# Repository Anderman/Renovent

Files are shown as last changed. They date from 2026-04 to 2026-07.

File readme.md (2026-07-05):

# Renovent 

## Installatie Screenshot
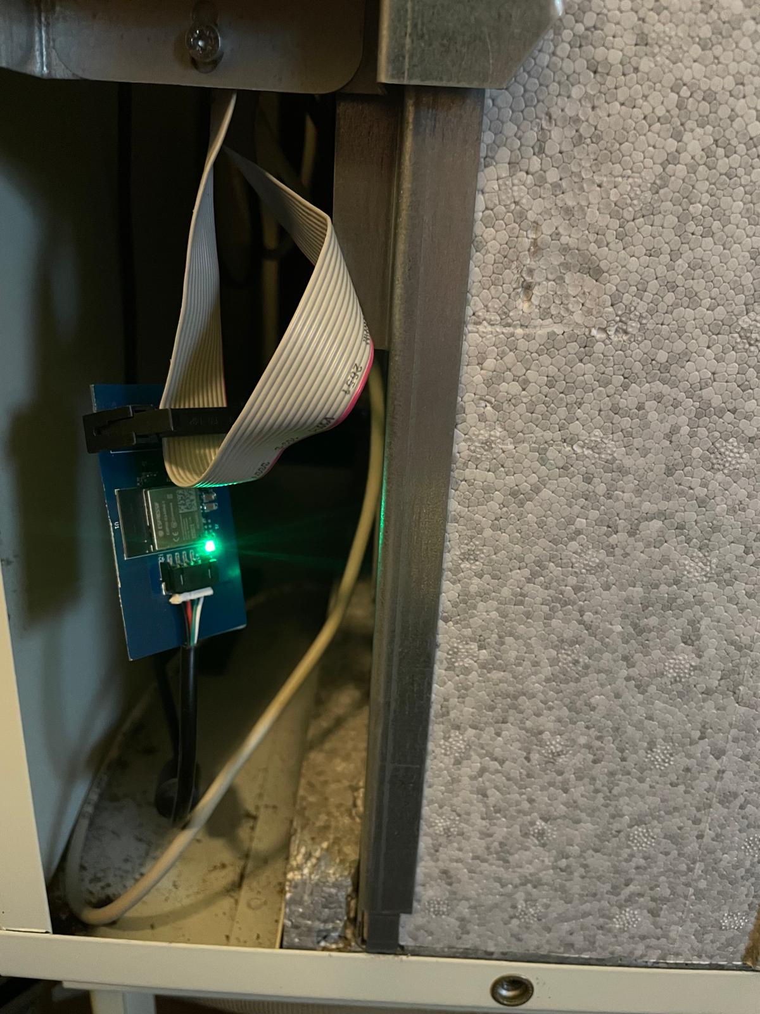
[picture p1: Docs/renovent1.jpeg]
Installatie connector aan flatkabel

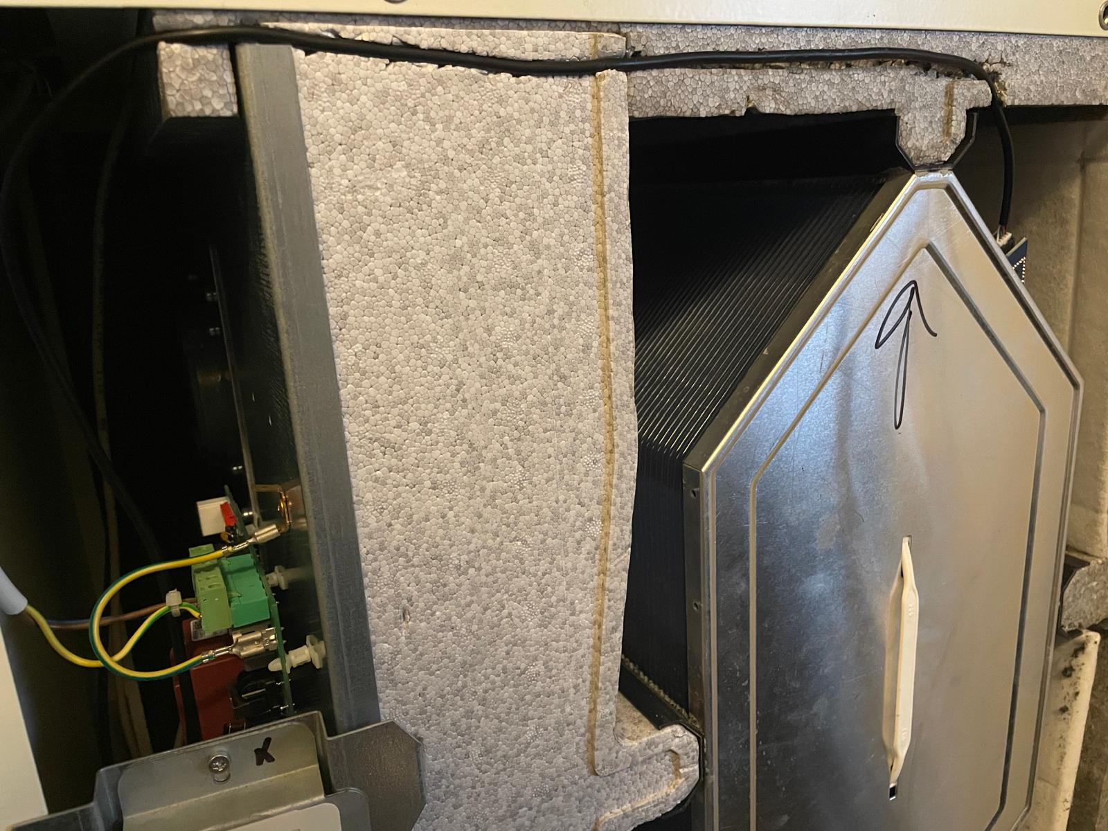
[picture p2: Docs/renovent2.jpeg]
Co2 sensor plaatsen


## Web interface
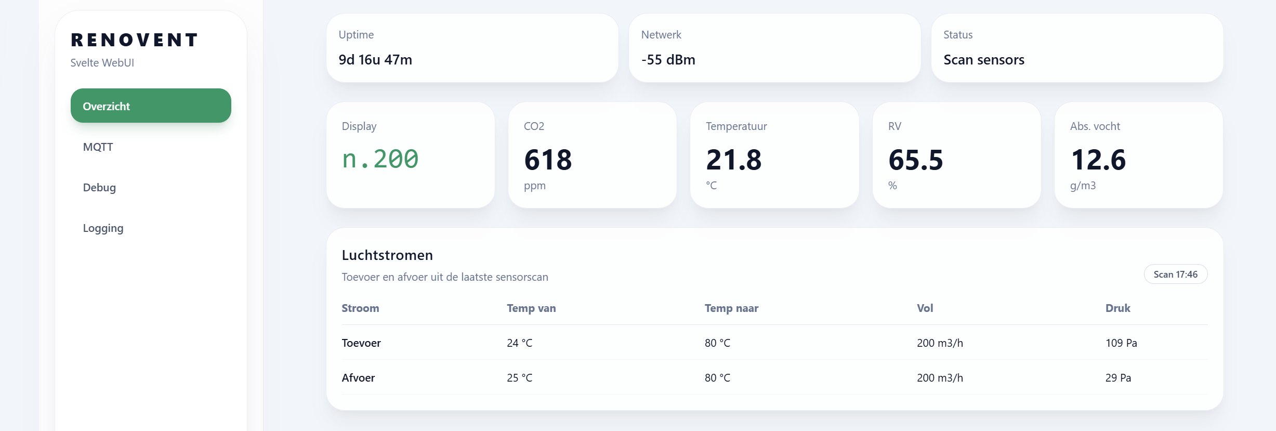
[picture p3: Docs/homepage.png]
homepage

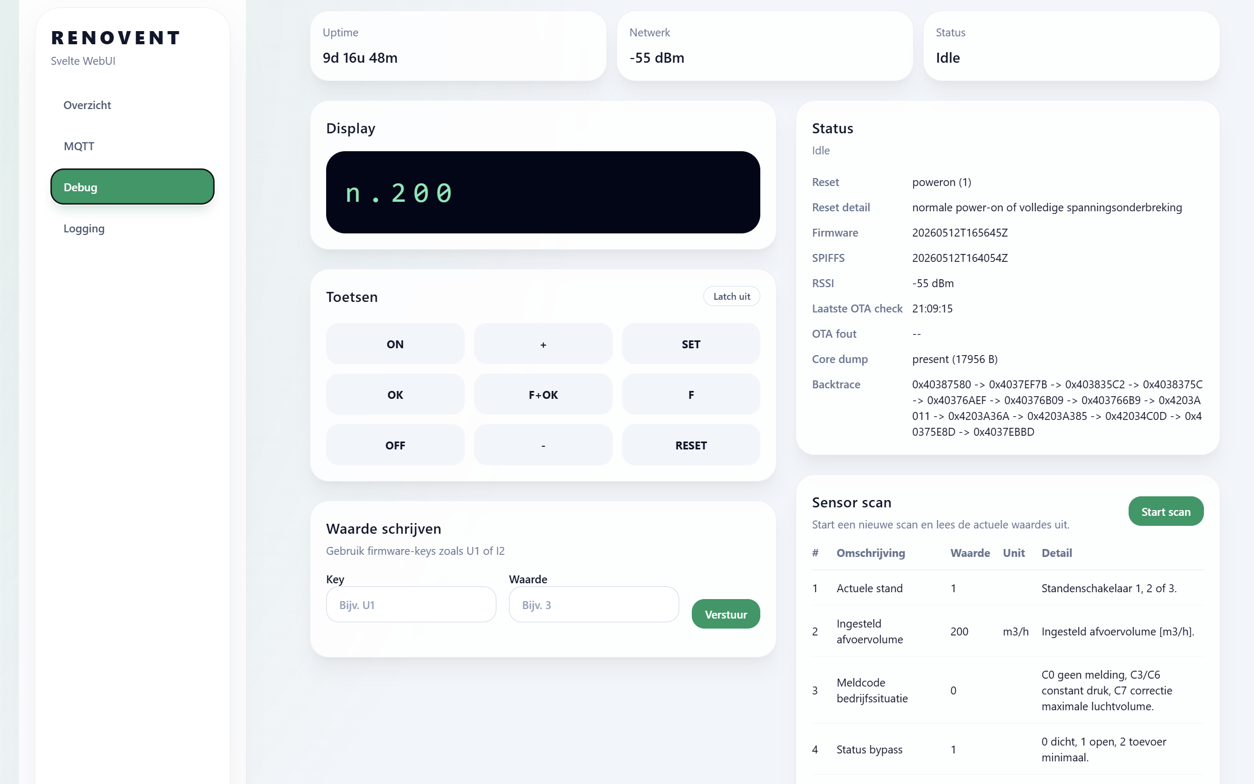
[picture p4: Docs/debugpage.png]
debug


## homeassistant
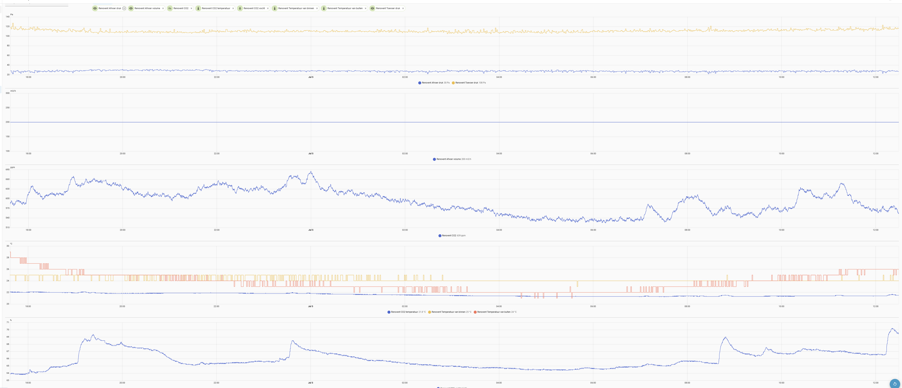
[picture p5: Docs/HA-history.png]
History

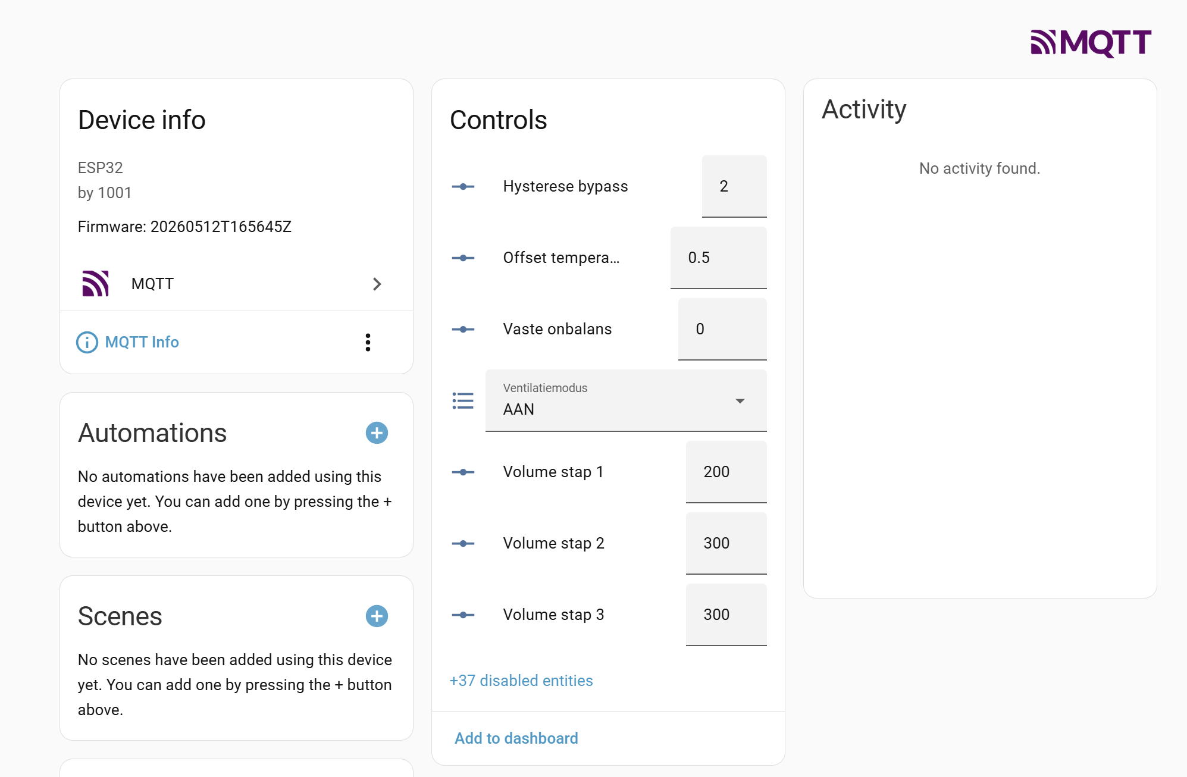
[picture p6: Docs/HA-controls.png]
Controls

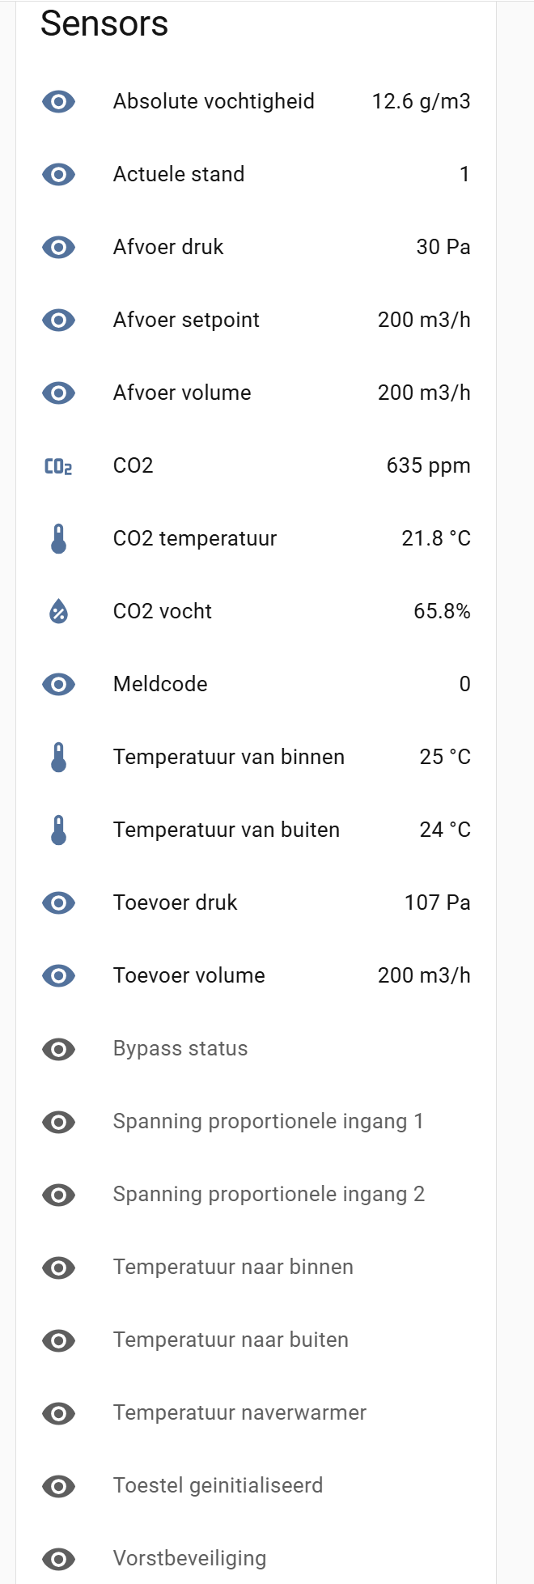
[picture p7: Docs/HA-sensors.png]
Sensors


# software documentatie
De originele controller is een display met toetsen en 1 IC
De IC zet een 3 bit counter om in 8 select lijnen van het display.

Display is een  [liteon](https://eu.mouser.com/datasheet/3/281/1/LTC_4627JS.pdf)
De 8 segementen worden in volgorde aan gestuurd met een freq van 500uS
Welke segmenten verlicht worden gaat met digit 1 - 4

Het programma zal dus het continue het display moeten uitlezen en wat er op staat omzetten in een 4 char array.
Hiervan met gebruik gemaakt worden van mapping om een 8 bit array om te zetten in een Char. Waarschijnlijk kan de DP los en hebben we een 7 bitarray naar char mapping nodig.

De switches werken als volgt

Er is 1 output Key_node.
sw1 (OK) = key_node=1 als C=1 (counter=1)
Sw2 (+ ) = key_node=1 als D=1 (counter=5)
Sw3 (F ) = key_node=1 als E=1 (counter=6)
Sw4 (- ) = key_node=1 als DP=1 (counter=3)

## ESP32 aansluiting

In het ESP32-schema worden de relevante signalen van de originele controller eerst via een SN74LVC245 naar 3V3 gebracht. De ESP32 ziet dus alleen de 3V3-varianten van deze signalen.

### Ingangen voor het uitlezen van display en toetsen

- BIT0 -> BIT0_3V3 -> GPIO35
- BIT1 -> BIT1_3V3 -> GPIO36
- BIT2 -> BIT2_3V3 -> GPIO37
- Digit1 -> Digit1_3V3 -> GPIO38
- Digit2 -> Digit2_3V3 -> GPIO39
- Digit3 -> Digit3_3V3 -> GPIO40
- Digit4 -> Digit4_3V3 -> GPIO41
- KEY_NODE -> KEY_NODE_3V3 -> GPIO42

Deze acht ingangen zijn voldoende om het gemultiplexte display en de toetsstatus te reconstrueren.

### Uitgang voor toets simulatie

- KEY_DOWN <- GPIO43

KEY_DOWN gaat via een BSS138-transistor naar de originele schakeling. Daarmee kan de ESP32 een toetsdruk simuleren zonder direct 5V op een GPIO te zetten.

### Overige aansluitingen op het ESP32-bord

- SDA_1 -> GPIO7
- SCL_1 -> GPIO8
- LED -> GPIO12

## Aanpak in software

De displaycontroller loopt elke 500 us door de 8 segment-selects. De software leest dus niet "digit 1", daarna "digit 2", enzovoort, maar leest per segment-select in een keer de toestand van alle 4 digitlijnen.

Concreet:

1. `BIT0`, `BIT1` en `BIT2` vormen samen een tellerwaarde van `0..7`.
2. Die tellerwaarde bepaalt welk segment op dat moment actief is.
3. Tegelijk wordt gekeken welke van `Digit1..Digit4` hoog zijn.
4. Voor het actieve segment wordt dat bit gezet in alle digits die op dat moment hoog zijn.
5. Na 8 select-stappen is er een compleet 4-digit frame opgebouwd.

De mapping van de tellerwaarde naar segment is:

| BIT2 BIT1 BIT0 | index | segment |
| --- | --- | --- |
| 0 0 0 | 0 | A |
| 0 0 1 | 1 | C |
| 0 1 0 | 2 | B |
| 0 1 1 | 3 | DP |
| 1 0 0 | 4 | F |
| 1 0 1 | 5 | D |
| 1 1 0 | 6 | E |
| 1 1 1 | 7 | G |

Schematisch ziet een volledige scan er zo uit:

```mermaid
flowchart LR
	A[GPIO snapshot] --> B[Lees BIT0..2]
	B --> C[Select-index 0..7]
	C --> D[Segment voor deze stap kiezen]
	D --> E{Lees Digit1..4 in dezelfde snapshot}
	E --> F[Zet dit ene segment in digit 1..4 als die hoog zijn]
	F --> G[Werk lopend frame bij]
	G --> H{Zijn alle 8 select-stappen gezien?}
	H -- nee --> A
	H -- ja --> I[4 complete digitmasks klaar]
	I --> J[Zet digitmasks om naar displaytekst]
```

Eén interrupt-snapshot doet dus niet alles. Per snapshot gebeurt maar dit:

- bepaal welk segment nu actief is via `BIT0..2`
- lees tegelijk welke van de 4 digitlijnen actief zijn
- zet dat ene segment in de digits die op dat moment hoog zijn

Pas nadat dit 8 keer gebeurd is, hebben we voor alle 4 digits een volledig segmentmasker.

Je kunt het ook zo lezen: we lezen niet "4 displays na elkaar", maar per segment in een keer alle 4 displays.

Voorbeeld:

- `BIT2..0 = 000` betekent segment `A`
- als op dat moment `Digit1` en `Digit3` hoog zijn, dan krijgt digit 1 en digit 3 het segment `A`
- bij de volgende select-stap wordt bijvoorbeeld segment `C` op dezelfde manier verdeeld over de 4 digits
- na alle 8 segmenten kennen we van elke digit het volledige segmentmasker

`KEY_NODE` wordt in diezelfde scan meegelezen. Een actieve key tijdens een specifieke select-index betekent een specifieke toets.

## Interrupt of polling

De huidige implementatie gebruikt juist een interrupt op `BIT0`.

Waarom:

- de select-bits veranderen snel genoeg dat polling onnodig veel jitter gaf
- de reader wil alle relevante lijnen op exact hetzelfde moment samplen
- daarom leest de ISR direct een volledige GPIO-snapshot en reconstrueert daaruit de actuele select-index, digitlijnen en `KEY_NODE`

De implementatie in `src/display_reader.cpp` werkt zo:

1. `BIT0` triggert `onBit0ChangeInterrupt()` op elke flank.
2. De ISR leest direct `GPIO.in1.val`, zodat alle ingangssignalen uit hetzelfde tijdsmoment komen.
3. Uit `BIT0..2` wordt de verwachte select-index bepaald.
4. Als een select-stap ontbreekt of de volgorde niet klopt, wordt het huidige frame weggegooid.
5. Na select `7` is een volledig frame klaar.
6. De hoofdloop publiceert pas een frame als twee opeenvolgende complete frames gelijk zijn.

Daardoor is de reader robuuster tegen timingglitches en worden half-opgebouwde displaybeelden niet gepubliceerd.

## Huidige softwarebasis

Er is nu een eerste ESP32 software-opzet toegevoegd in de map `src`.

- `src/main.cpp` start WiFi, de webserver en de display reader.
- `src/wifiSetup.*` gebruikt WiFiManager, net als in het andere project.
- `src/display_reader.*` leest BIT0..2, Digit1..4 en KEY_NODE in en bouwt daar een stabiel displayframe van op.
- `src/webui/webui.*` publiceert een simpele HTTP API en serveert statische bestanden uit SPIFFS.
- `data/index.html` is een eenvoudige debugpagina.

### Webinterface

Na boot:

- hoofd-UI op poort 80
- WiFiManager portal op poort 8080

Beschikbare endpoints:

- `GET /api/status`
- `POST /api/keydown`

`/api/status` geeft onder andere terug:

- gedecodeerde displaytekst
- actieve toets op basis van `KEY_NODE`
- WiFi-status

### PlatformIO

Er is ook een `partitions/default.csv` toegevoegd zodat de SPIFFS data-partitie beschikbaar is voor de webpagina.

Voor lokaal gebruik zijn deze commando's relevant:

1. `platformio run`
2. `platformio run --target buildfs`
3. `platformio run --target uploadfs`
4. `platformio run --target upload`

### OTA artifacts lokaal bouwen

De automatische firmware-update leest OTA-bestanden uit `release/firmware`, `release/spiffs` en `release/latest.json`.

Deze artifacts worden lokaal gegenereerd door `scripts/generate_build_info.py`, dat als PlatformIO build hook meeloopt. De hook:

- berekent een aparte hash voor `src` en `data`
- bewaart per component precies een markerbestand `*.hash` in `src` en `ui-hashes`
- schrijft alleen een nieuwe build-id als de hash van die component gewijzigd is
- kopieert de nieuwe `.bin` naar `release/firmware` of `release/spiffs`
- werkt daarna `release/latest.json` bij

Voor een volledige lokale OTA release bouw je beide artifacts:

1. `platformio run -e esp32s3mini_ota`
2. `platformio run -e esp32s3mini_ota -t buildfs`

Daarna kun je de bijgewerkte bestanden in `release/` zelf committen of op een andere manier publiceren, zolang `release/latest.json` en de bijbehorende `.bin` bestanden bereikbaar blijven voor de ESP32.

### Backtrace decoderen

Een ESP32-S3 backtrace uit de WebUI of seriele output kun je direct tegen de actuele firmware-ELF symboliseren met:

```powershell
.\scripts\decode_backtrace.ps1 "0x4037EF71 -> 0x40377C96 -> 0x40376AEF"
```

Het script gebruikt standaard:

- `.pio/build/esp32s3mini_ota/firmware.elf`
- de PlatformIO `xtensa-esp32s3-elf-addr2line.exe`

Belangrijk: decode altijd tegen de ELF van dezelfde firmware-build als waarmee de crash is ontstaan, anders kloppen functies en regelnummers mogelijk niet.

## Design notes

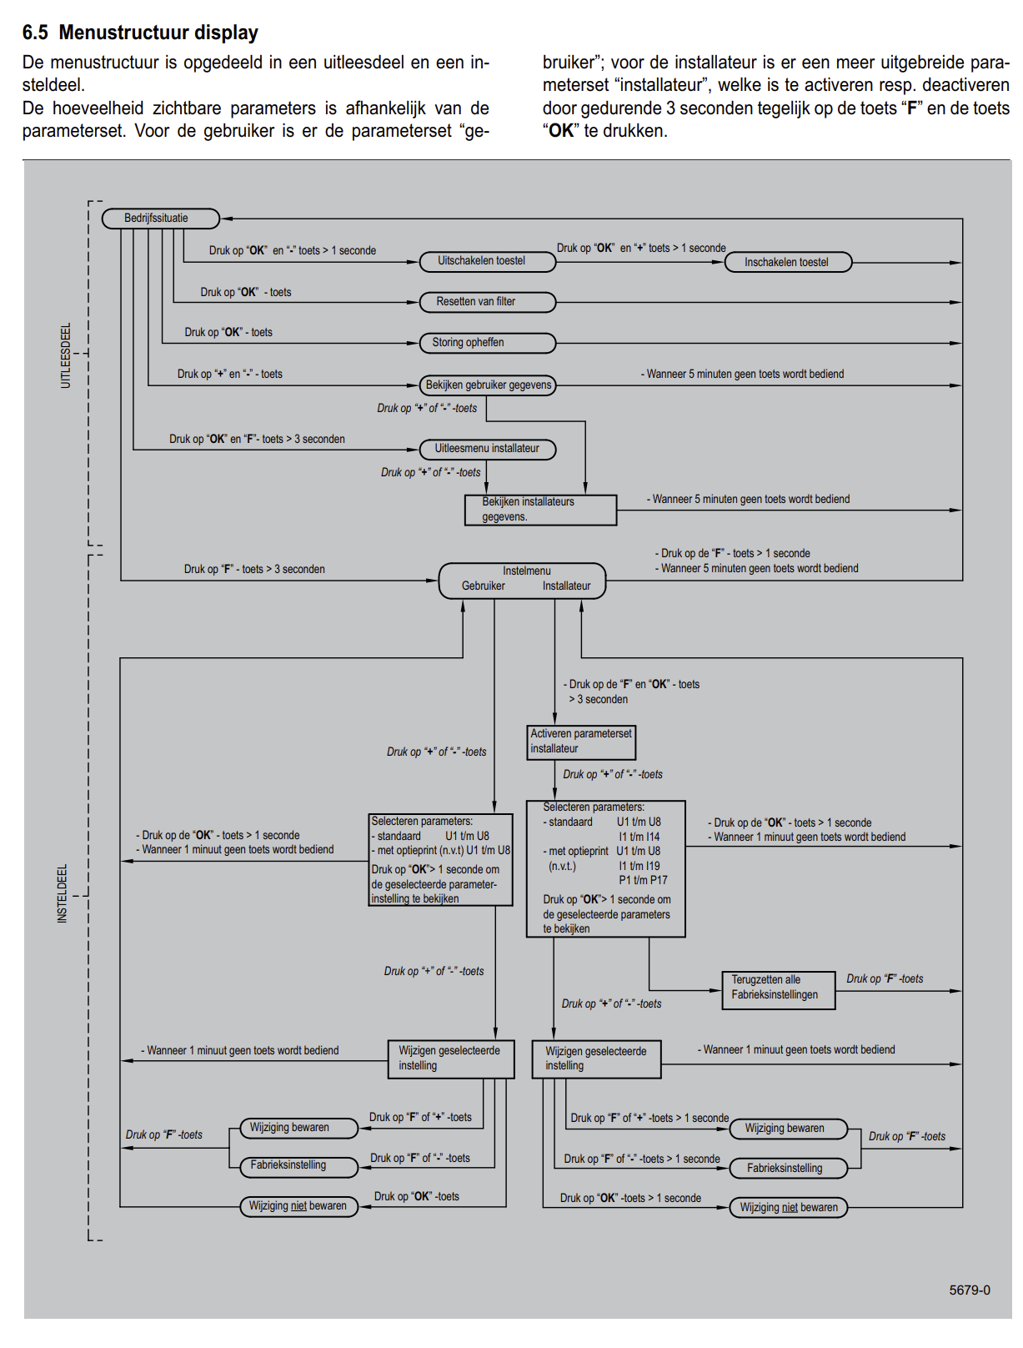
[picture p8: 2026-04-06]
Docs/H6 P20.png

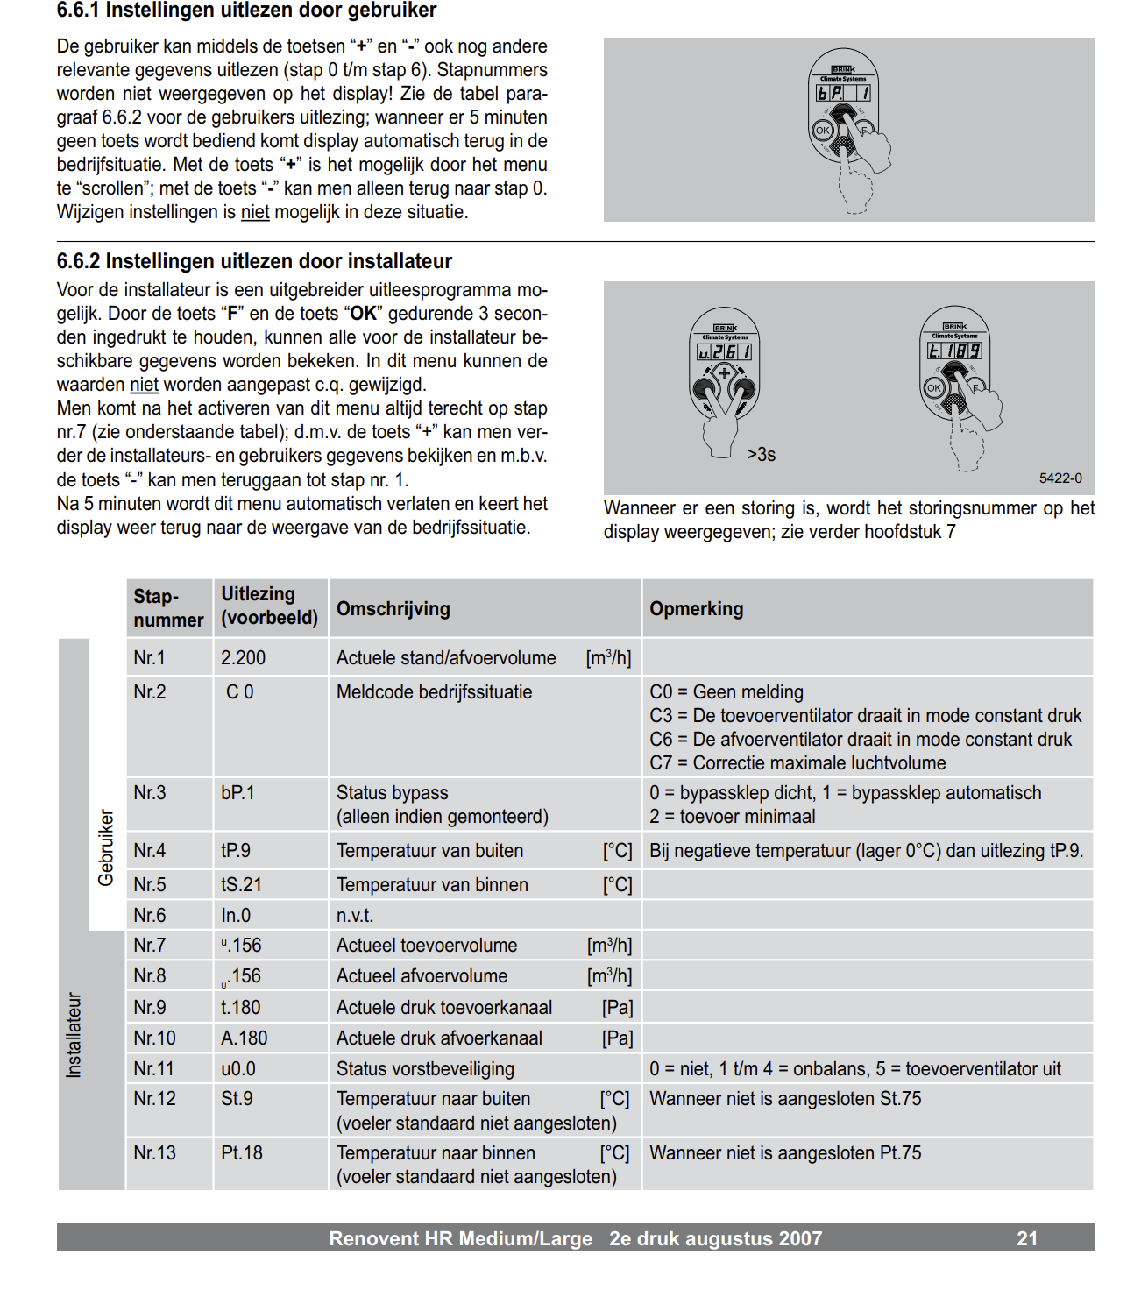
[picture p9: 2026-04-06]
Docs/H6 p21.png

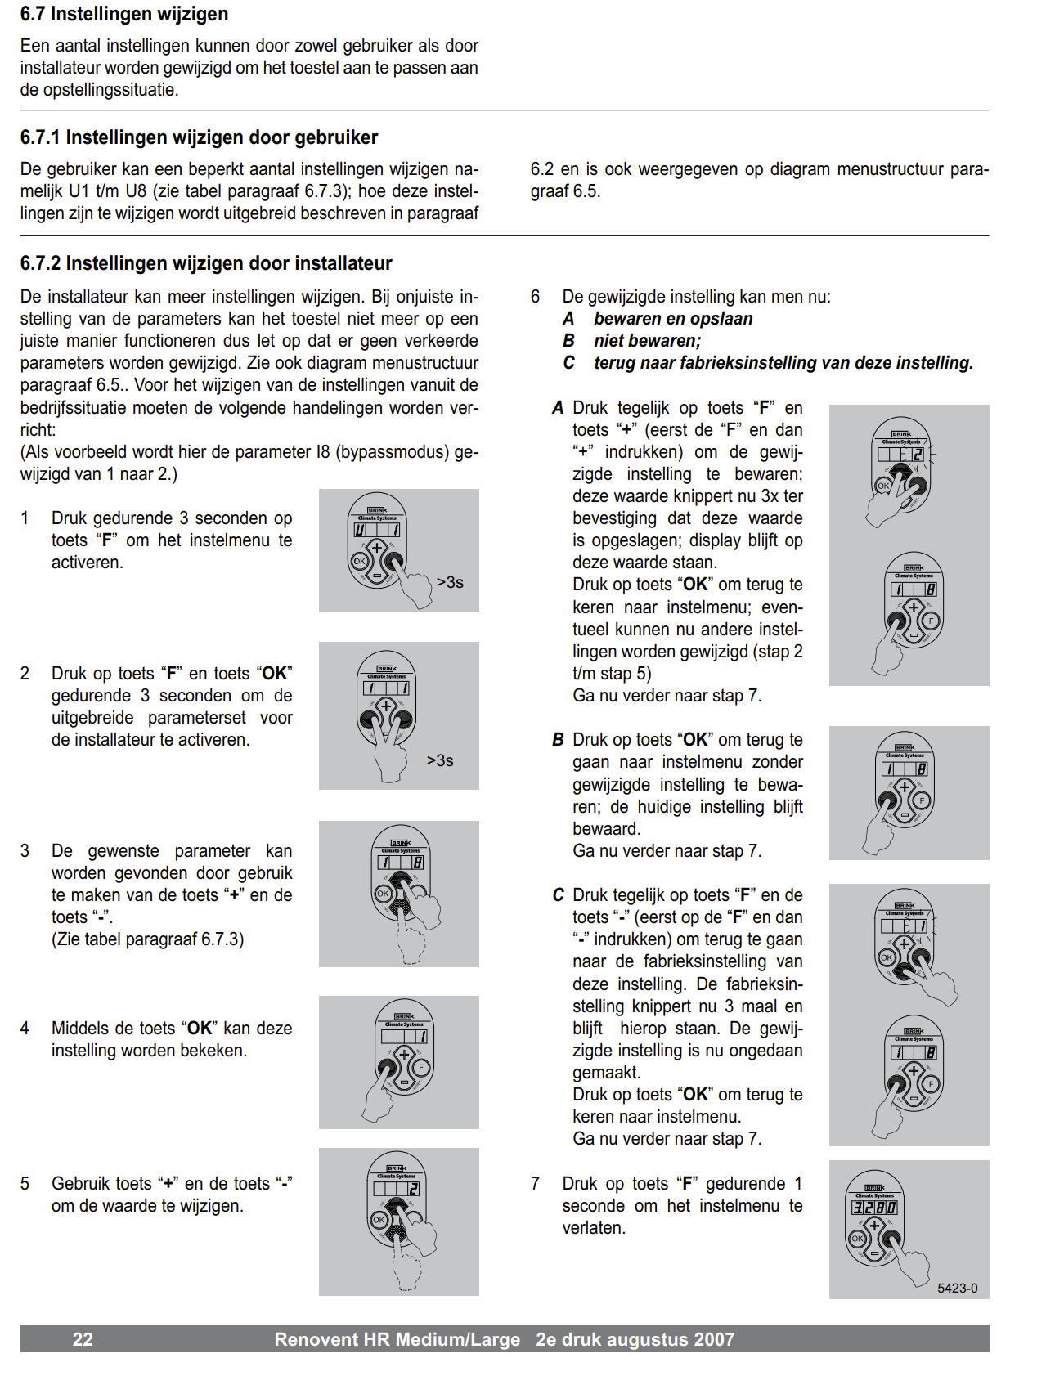
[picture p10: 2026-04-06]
Docs/H6 p22.png

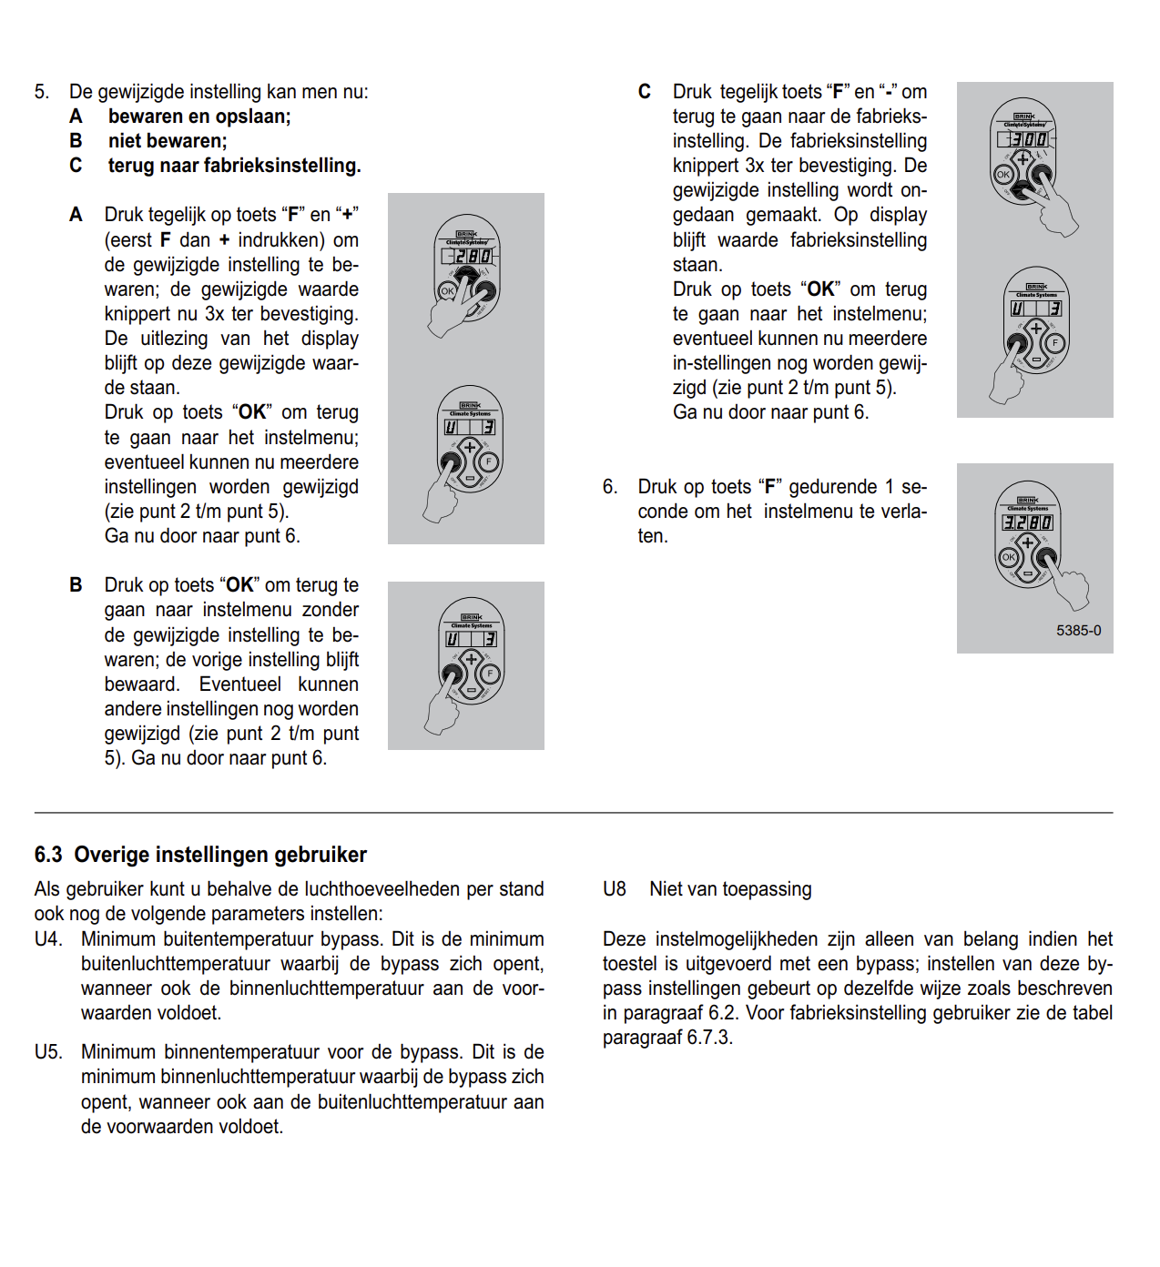
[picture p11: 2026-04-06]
Docs/H6 p18.png

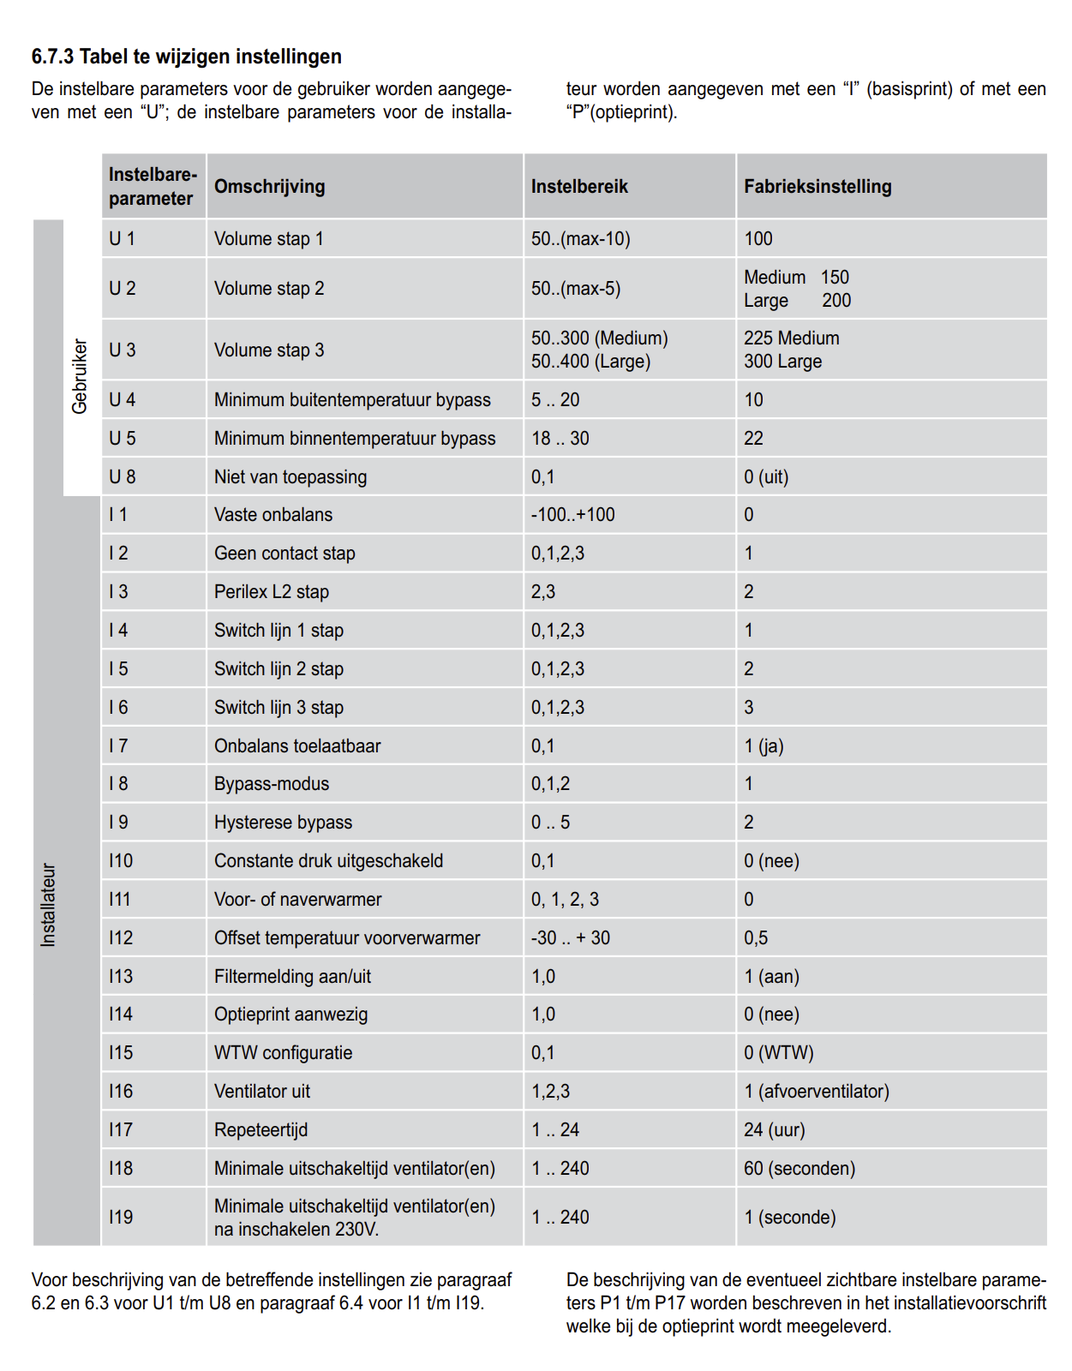
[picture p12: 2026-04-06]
Docs/H6 P23.png

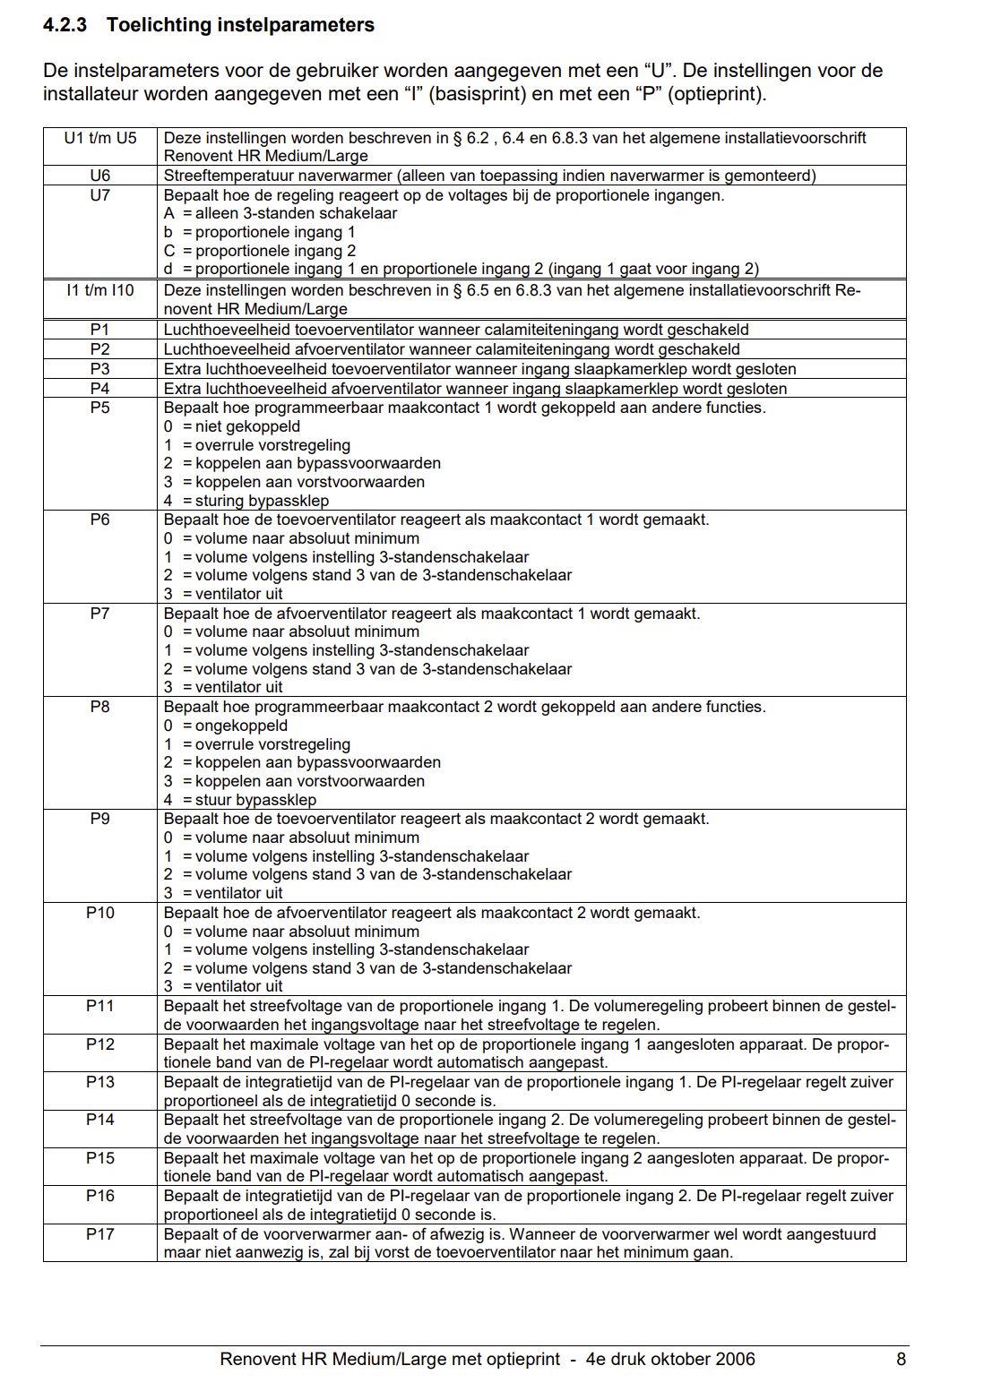
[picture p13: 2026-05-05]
Docs/4.3.2 P8.png

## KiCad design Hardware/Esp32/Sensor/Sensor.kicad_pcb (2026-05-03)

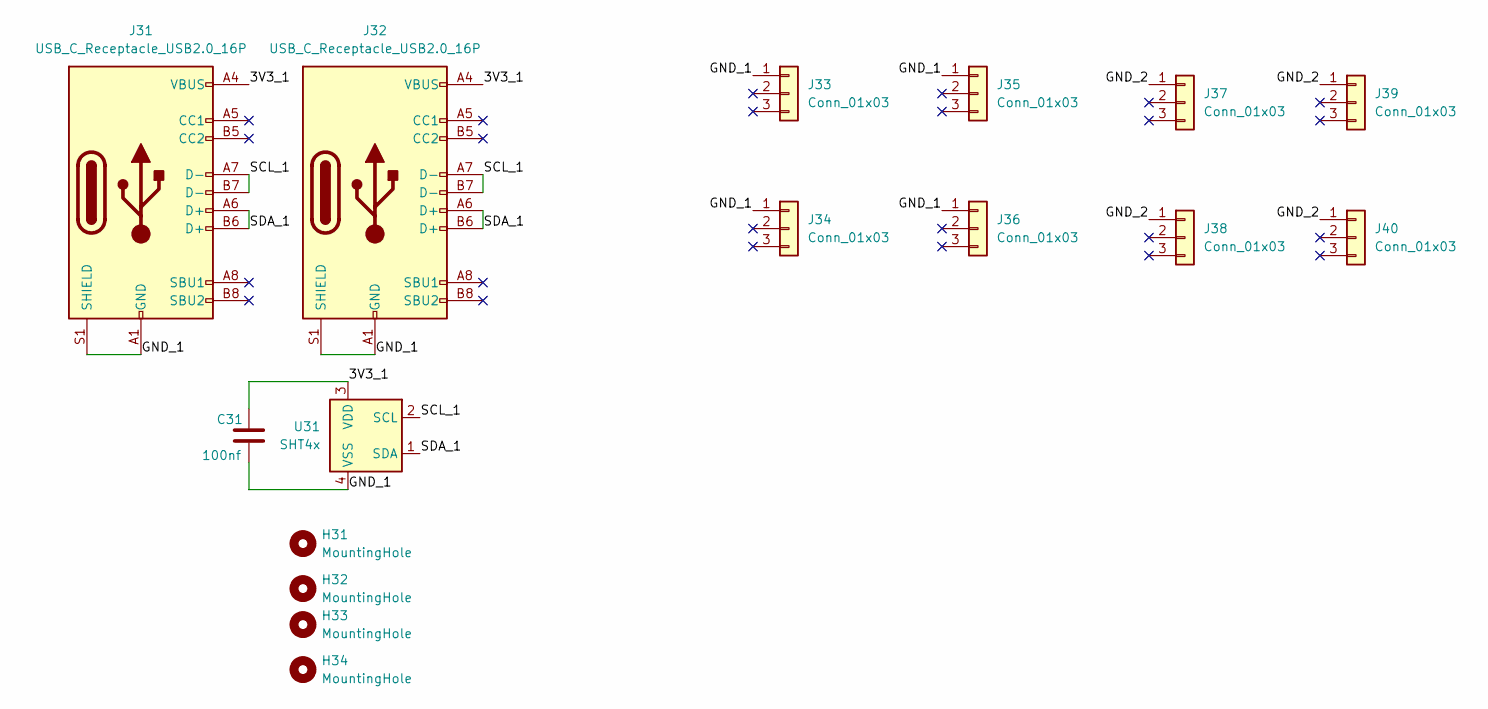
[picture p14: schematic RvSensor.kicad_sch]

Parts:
C31: 100nf; C_0402_1005Metric; LCSC C1525
H31, H32, H33, H34: MountingHole; MountingHole_2.5mm
J31, J32: USB_C_Receptacle_USB2.0_16P; USB_C_Receptacle_HRO_TYPE-C-31-M-12; LCSC C36936538
J33, J34, J35, J36: Conn_01x03; PinSocket_1x03_P2.00mm_Vertical_female_C2935967; LCSC C2935967
J37, J38, J39, J40: Conn_01x03; PinHeader_1x03_P2.00mm_Vertical_male_C541857; LCSC C541857
U31: SHT4x; Sensirion_DFN-4_1.5x1.5mm_P0.8mm_SHT4x_NoCentralPad; LCSC C7461852

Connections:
/RvSensor/3V3_1: C31.1, J31.A4 (VBUS), J31.A9 (VBUS), J31.B4 (VBUS), J31.B9 (VBUS), J32.A4 (VBUS), J32.A9 (VBUS), J32.B4 (VBUS), J32.B9 (VBUS), U31.3 (VDD)
/RvSensor/GND_1: C31.2, J31.A1 (GND), J31.A12 (GND), J31.B1 (GND), J31.B12 (GND), J31.S1 (SHIELD), J32.A1 (GND), J32.A12 (GND), J32.B1 (GND), J32.B12 (GND), J32.S1 (SHIELD), J33.1, J34.1, J35.1, J36.1, U31.4 (VSS)
/RvSensor/GND_2: J37.1, J38.1, J39.1, J40.1
/RvSensor/SCL_1: J31.A7 (D-), J31.B7 (D-), J32.A7 (D-), J32.B7 (D-), U31.2 (SCL)
/RvSensor/SDA_1: J31.A6 (D+), J31.B6 (D+), J32.A6 (D+), J32.B6 (D+), U31.1 (SDA)

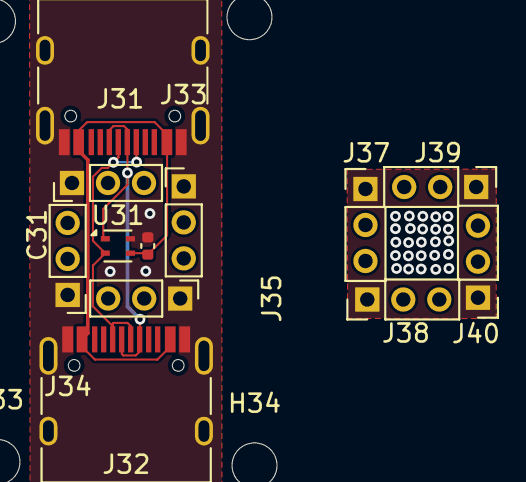
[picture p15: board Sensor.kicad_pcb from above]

Board: 2 copper layers, 16 parts (0 on the bottom side), 5 nets.

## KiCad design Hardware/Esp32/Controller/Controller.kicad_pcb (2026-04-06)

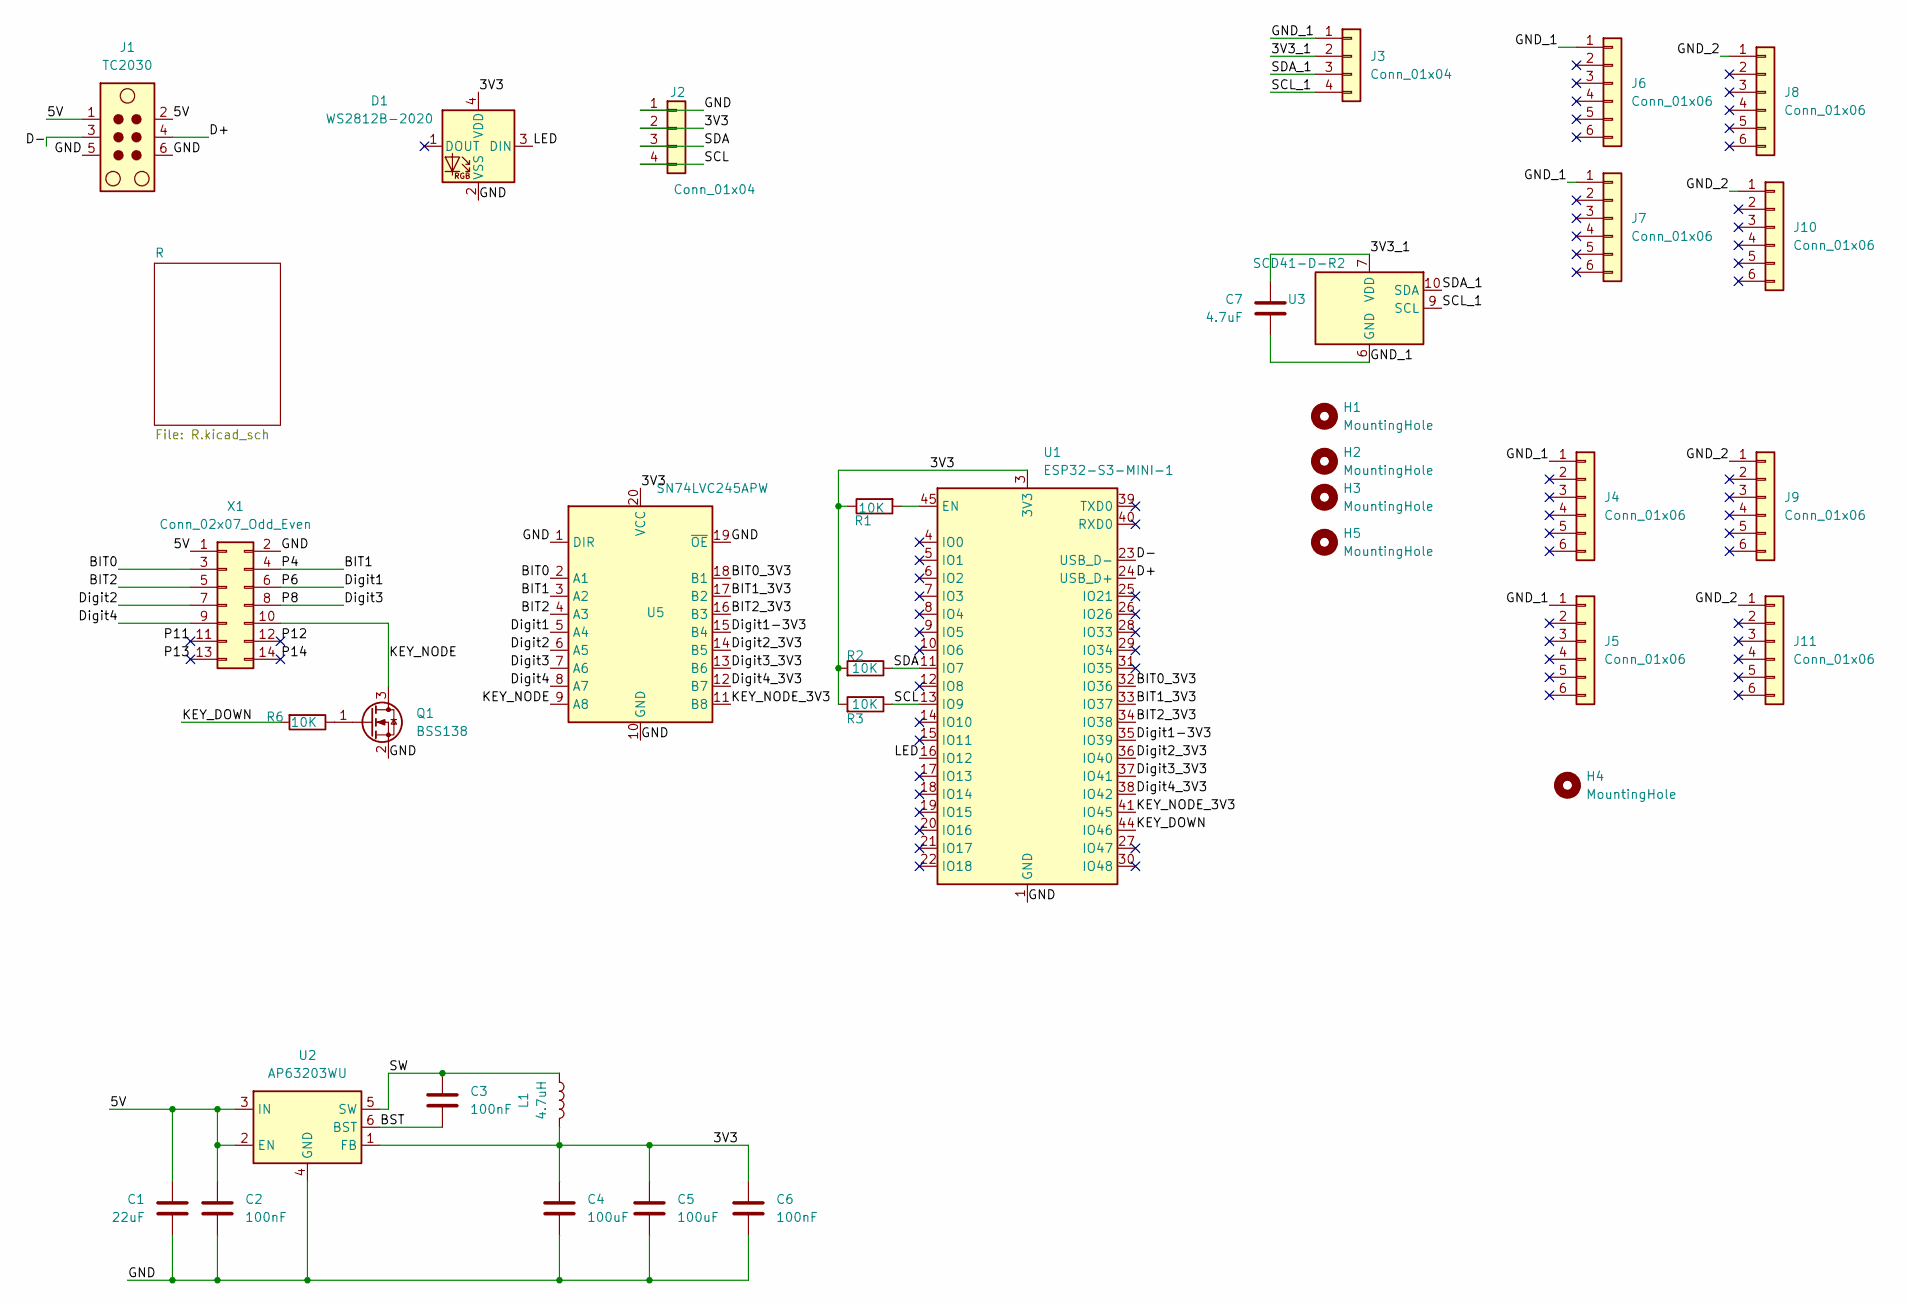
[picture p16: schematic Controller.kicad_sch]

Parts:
C1: 22uF; C_0805_2012Metric; LCSC C5674
C2, C3: 100nF; C_0603_1608Metric; LCSC C56476
C4, C5: 100uF; C_1206_3216Metric; LCSC C15008
C6: 100nF; C_0201_0603Metric; LCSC C76934
C7: 4.7uF; C_0603_1608Metric; LCSC C19666
D1: WS2812B-2020; LED_WS2812B-2020_2x2.2mm; LCSC C965555
H1, H2, H3, H5: MountingHole; MountingHole_2.5mm
H4: MountingHole; MountingHole_7mm
J1: TC2030; Tag-Connect_TC2030-IDC-NL_2x03_P1.27mm_Vertical
J2, J3: Conn_01x04; JST_PH_S4B-PH-SM4-TB_1x04-1MP_P2.00mm_Horizontal; LCSC C157926
J4, J5, J6, J7: Conn_01x06; PinSocket_1x06_P2.00mm_Vertical_female_C7499363; LCSC C7499363
J8, J9, J10, J11: Conn_01x06; PinHeader_1x06_P2.00mm_Vertical_male_C706993; LCSC C706993
L1: 4.7uH; L_Bourns-SRN4018; LCSC C5159668
Q1: BSS138; SOT-23; LCSC C20917
R1, R2, R3, R6: 10K; R_0402_1005Metric; LCSC C25744
U1: ESP32-S3-MINI-1; LCSC C3013941
U2: AP63203WU; TSOT-23-6; LCSC C780769
U3: SCD41-D-R2; Sensirion_SCD4x-1EP_10.1x10.1mm_P1.25mm_EP4.8x4.8mm; LCSC C3659294
U5: SN74LVC245APW; TSSOP-20_4.4x6.5mm_P0.65mm; LCSC C45384750
X1: Conn_02x07_Odd_Even; IDC-Header_2x07_P2.54mm_Vertical; LCSC C9037

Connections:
/3V3: C4.1, C5.1, C6.1, D1.4 (VDD), J2.2, L1.2, R1.1, R2.2, R3.2, U1.3 (3V3), U2.1 (FB), U5.20 (VCC)
/3V3_1: C7.1, J3.2, U3.7 (VDD), U3.19 (VDD)
/5V: C1.1, C2.1, J1.1, J1.2, U2.2 (EN), U2.3 (IN), X1.1
/BIT0: U5.2 (A1), X1.3
/BIT0_3V3: U1.32 (IO36), U5.18 (B1)
/BIT1: U5.3 (A2), X1.4
/BIT1_3V3: U1.33 (IO37), U5.17 (B2)
/BIT2: U5.4 (A3), X1.5
/BIT2_3V3: U1.34 (IO38), U5.16 (B3)
/BST: C3.2, U2.6 (BST)
/D+: J1.4, U1.24 (USB_D+)
/D-: J1.3, U1.23 (USB_D-)
/Digit1: U5.5 (A4), X1.6
/Digit1-3V3: U1.35 (IO39), U5.15 (B4)
/Digit2: U5.6 (A5), X1.7
/Digit2_3V3: U1.36 (IO40), U5.14 (B5)
/Digit3: U5.7 (A6), X1.8
/Digit3_3V3: U1.37 (IO41), U5.13 (B6)
/Digit4: U5.8 (A7), X1.9
/Digit4_3V3: U1.38 (IO42), U5.12 (B7)
/GND: C1.2, C2.2, C4.2, C5.2, C6.2, D1.2 (VSS), J1.5, J1.6, J2.1, Q1.2 (S), U1.1 (GND), U1.2 (GND), U1.42 (GND), U1.43 (GND), U1.46 (GND), U1.47 (GND), U1.48 (GND), U1.49 (GND), U1.50 (GND), U1.51 (GND), U1.52 (GND), U1.53 (GND), U1.54 (GND), U1.55 (GND), U1.56 (GND), U1.57 (GND), U1.58 (GND), U1.59 (GND), U1.60 (GND), U1.61 (GND), U1.62 (GND), U1.63 (GND), U1.64 (GND), U1.65 (GND), U2.4 (GND), U5.1 (DIR), U5.10 (GND), U5.19 (~OE), X1.2
/GND_1: C7.2, J3.1, J4.1, J5.1, J6.1, J7.1, U3.6 (GND), U3.20 (GND), U3.21 (GND)
/GND_2: J8.1, J9.1, J10.1, J11.1
/KEY_DOWN: R6.2, U1.44 (IO46)
/KEY_NODE: Q1.3 (D), U5.9 (A8), X1.10
/KEY_NODE_3V3: U1.41 (IO45), U5.11 (B8)
/LED: D1.3 (DIN), U1.16 (IO12)
/P11: X1.11
/P12: X1.12
/P13: X1.13
/P14: X1.14
/SCL: J2.4, R3.1, U1.13 (IO9)
/SCL_1: J3.4, U3.9 (SCL)
/SDA: J2.3, R2.1, U1.11 (IO7)
/SDA_1: J3.3, U3.10 (SDA)
/SW: C3.1, L1.1, U2.5 (SW)
unnamed: Q1.1 (G), R6.1
unnamed: R1.2, U1.45 (EN)

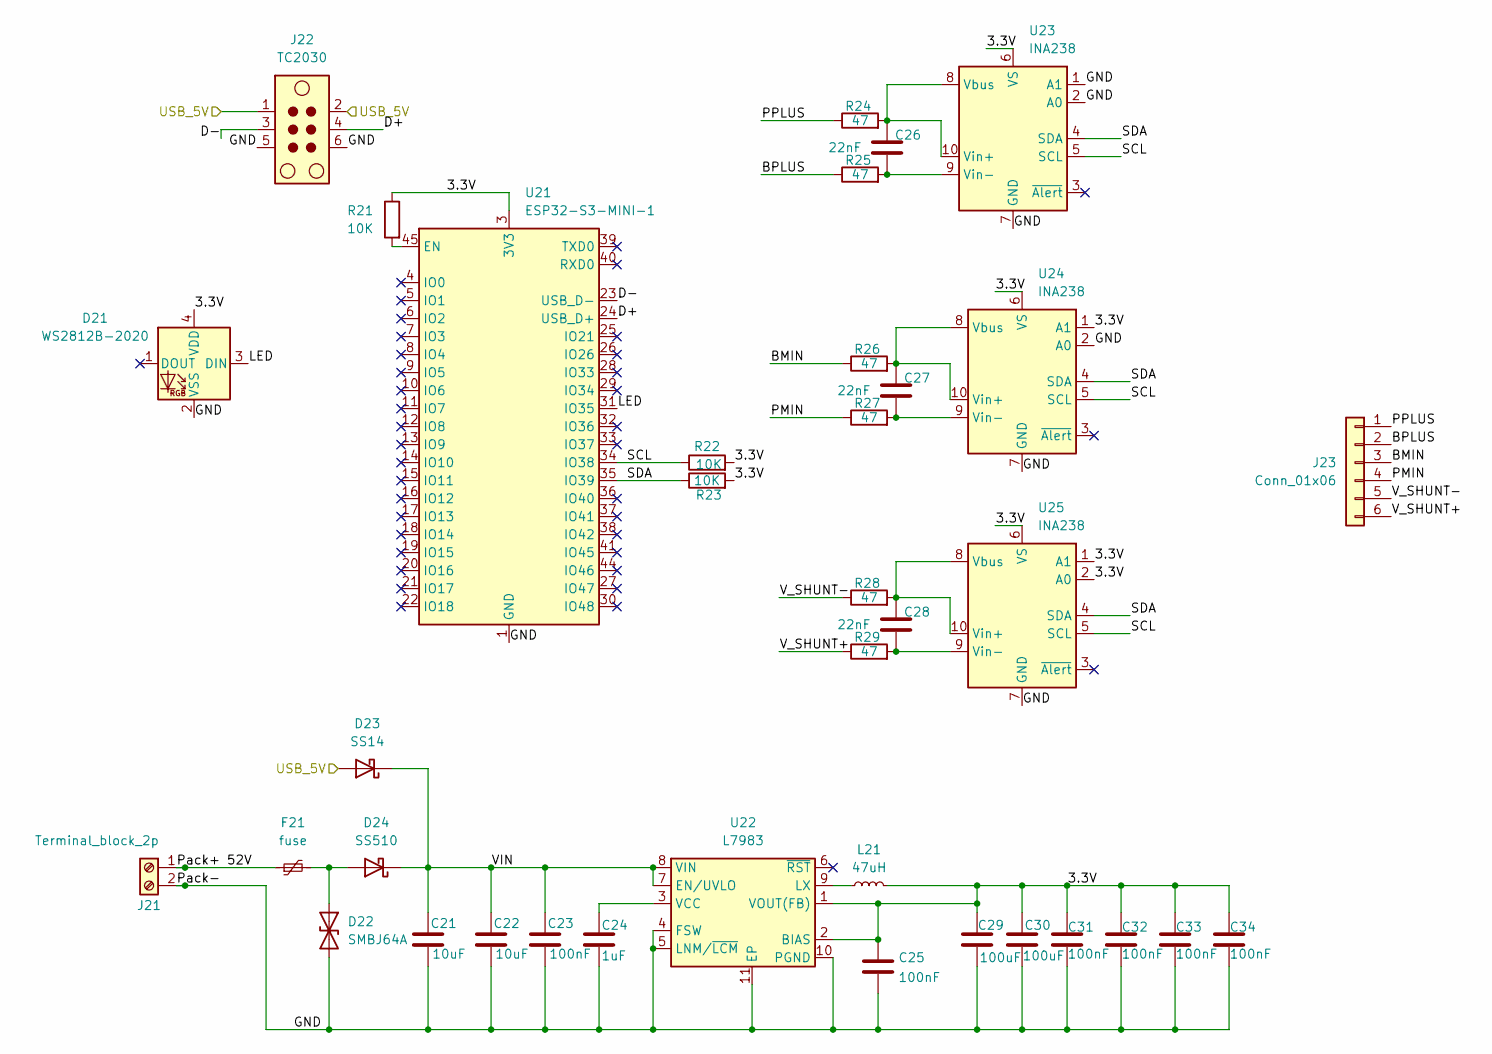
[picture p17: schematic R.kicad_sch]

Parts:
C21, C22: 10uF; C_1210_3225Metric; LCSC C576517
C23: 100nF; C_0402_1005Metric; LCSC C162178
C24: 1uF; C_0603_1608Metric; LCSC C23829972
C25, C31, C32, C33, C34: 100nF; C_0201_0603Metric; LCSC C76934
C26, C27, C28: 22nF; C_0603_1608Metric; LCSC C161234
C29, C30: 100uF; C_1206_3216Metric; LCSC C15008
D21: WS2812B-2020; LED_WS2812B-2020_2x2.2mm; LCSC C965555
D22: SMBJ64A; D_SMB; LCSC C19077594
D23: SS14; D_SMA; LCSC C2480
D24: SS510; D_SMA; LCSC C18199171
F21: fuse; Fuse_1812_4532Metric; LCSC C2830263
J21: Terminal_block_2p; TerminalBlock_Phoenix_MKDS-1-2-3.81_1x02_P3.81mm_Horizontal; LCSC C5188452
J22: TC2030; Tag-Connect_TC2030-IDC-NL_2x03_P1.27mm_Vertical
J23: Conn_01x06; JST_PH_S6B-PH-SM4-TB_1x06-1MP_P2.00mm_Horizontal; LCSC C265405
L21: 47uH; L_APV_ANR5040; LCSC C167974
R21: 10K; R_0402_1005Metric; LCSC C25744
R22, R23: 10K; R_0603_1608Metric; LCSC C25804
R24, R25, R26, R27, R28, R29: 47; R_0603_1608Metric; LCSC C23182
U21: ESP32-S3-MINI-1; LCSC C3013941
U22: L7983; TDFN-10-1EP_3x3mm_P0.5mm; LCSC C1518764
U23, U24, U25: INA238; VSSOP-10_3x3mm_P0.5mm; LCSC C2868250

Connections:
/R/3.3V: C25.1, C29.1, C30.1, C31.1, C32.1, C33.1, C34.1, D21.4 (VDD), L21.2, R21.1, R22.2, R23.2, U21.3 (3V3), U22.1 (VOUT(FB)), U22.2 (BIAS), U23.6 (VS), U24.1 (A1), U24.6 (VS), U25.1 (A1), U25.2 (A0), U25.6 (VS)
/R/BMIN: J23.3, R26.1
/R/BPLUS: J23.2, R25.1
/R/D+: J22.4, U21.24 (USB_D+)
/R/D-: J22.3, U21.23 (USB_D-)
/R/GND: C21.2, C22.2, C23.2, C24.2, C25.2, C29.2, C30.2, C31.2, C32.2, C33.2, C34.2, D21.2 (VSS), D22.2 (A2), J21.2, J22.5, J22.6, U21.1 (GND), U21.2 (GND), U21.42 (GND), U21.43 (GND), U21.46 (GND), U21.47 (GND), U21.48 (GND), U21.49 (GND), U21.50 (GND), U21.51 (GND), U21.52 (GND), U21.53 (GND), U21.54 (GND), U21.55 (GND), U21.56 (GND), U21.57 (GND), U21.58 (GND), U21.59 (GND), U21.60 (GND), U21.61 (GND), U21.62 (GND), U21.63 (GND), U21.64 (GND), U21.65 (GND), U22.4 (FSW), U22.5 (LNM/~LCM), U22.10 (PGND), U22.11 (EP), U23.1 (A1), U23.2 (A0), U23.7 (GND), U24.2 (A0), U24.7 (GND), U25.7 (GND)
/R/LED: D21.3 (DIN), U21.31 (IO35)
/R/PMIN: J23.4, R27.1
/R/PPLUS: J23.1, R24.1
/R/Pack+ 52V: F21.1, J21.1
/R/SCL: R22.1, U21.34 (IO38), U23.5 (SCL), U24.5 (SCL), U25.5 (SCL)
/R/SDA: R23.1, U21.35 (IO39), U23.4 (SDA), U24.4 (SDA), U25.4 (SDA)
/R/USB_5V: D23.2 (A), J22.1, J22.2
/R/VIN: C21.1, C22.1, C23.1, D23.1 (K), D24.1 (K), U22.7 (EN/UVLO), U22.8 (VIN)
/R/V_SHUNT+: J23.6, R29.1
/R/V_SHUNT-: J23.5, R28.1
unnamed: D22.1 (A1), D24.2 (A), F21.2
unnamed: R21.2, U21.45 (EN)
unnamed: L21.1, U22.9 (LX)
unnamed: C24.1, U22.3 (VCC)
unnamed: C26.1, R24.2, U23.8 (Vbus), U23.10 (Vin+)
unnamed: C26.2, R25.2, U23.9 (Vin-)
unnamed: C27.1, R26.2, U24.8 (Vbus), U24.10 (Vin+)
unnamed: C27.2, R27.2, U24.9 (Vin-)
unnamed: C28.1, R28.2, U25.8 (Vbus), U25.10 (Vin+)
unnamed: C28.2, R29.2, U25.9 (Vin-)

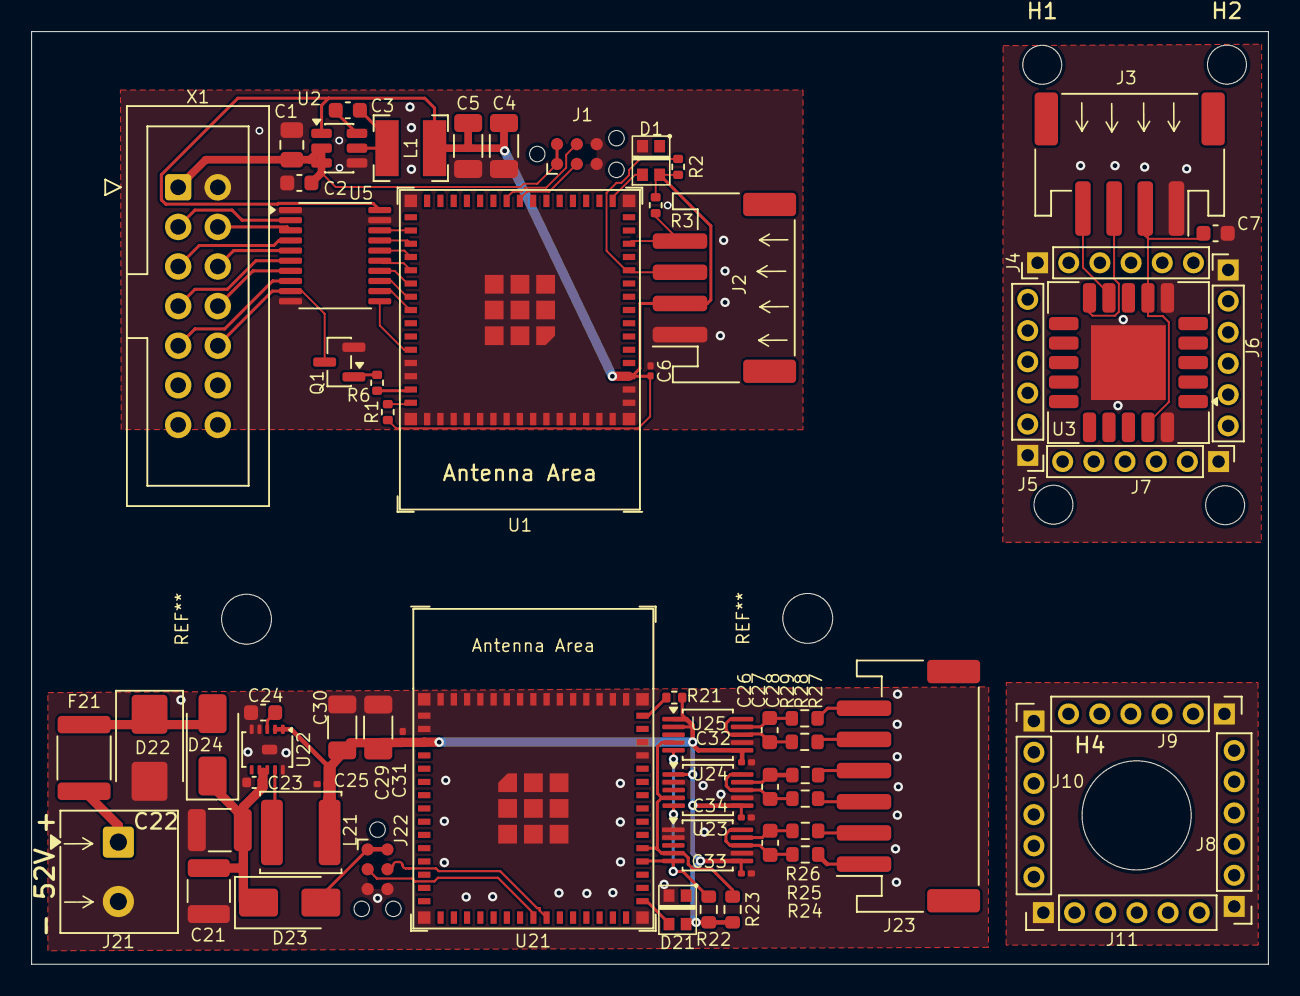
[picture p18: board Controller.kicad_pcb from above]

Board: 2 copper layers, 79.3 x 59.8 mm, 72 parts (0 on the bottom side), 60 nets.

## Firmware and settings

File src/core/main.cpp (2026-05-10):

#include <Arduino.h>
#include <WiFi.h>

#include "hardware/co2_sensor.h"
#include "display/display_reader.h"
#include "menu/sensors_menu.h"
#include "input/key_writer.h"
#include "input/keypad.h"
#include "mqtt/mqtt_config.h"
#include "mqtt/mqtt_runtime.h"
#include "ota/ota.h"
#include "ota/auto_update.h"
#include "core/reset_info.h"
#include "menu/setting_writer.h"
#include "hardware/status_led.h"
#include "menu/settings_menu.h"
#include "webui/webui.h"
#include "core/wifiSetup.h"

void setup()
{
  Serial.begin(115200);
  delay(1000);
  resetInfoSetup();
  mqttConfigSetup();
  mqttRuntimeSetup();
  Serial.println();
  Serial.println("[renovent] boot");
  resetInfoPrintToSerial();

  statusLedSetup();
  statusLedSetRgb(64, 0, 0);
  setupWifi();
  setupOta();
  setupAutoUpdate();
  statusLedSetRgb(0, 64, 0);

  displayReaderSetup();
  co2SensorSetup();
  keyWriterSetup();
  sensorsMenuSetup();
  settingWriterSetup();
  settingsMenuSetup();
  setupWebUi();
  setupWifiConfigPage();

  Serial.print("[renovent] webui: http://");
  Serial.println(WiFi.localIP());
  Serial.println("[renovent] wifi portal: http://<ip>:8080");
}

void loop()
{
  displayReaderLoop();
  co2SensorLoop();
  keyWriterLoop();
  sensorsMenuLoop();
  settingWriterLoop();
  settingsMenuLoop();
  otaLoop();
  autoUpdateLoop();
  webUiLoop();
  mqttRuntimeLoop();
  wifiManagerLoop();
}

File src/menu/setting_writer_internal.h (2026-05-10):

#pragma once

#include <Arduino.h>

namespace setting_writer_internal
{

    struct SettingWriteRequest
    {
        char key[4] = {0};
        int32_t targetValue = 0;
        bool targetHasNumericValue = false;
        char targetDisplayValue[9] = {0};
    };

    struct SettingWriterState
    {
        bool running = false;
        uint8_t currentStepIndex = 0;
        uint32_t phaseStartedMs = 0;
        uint32_t invalidDisplayStartedMs = 0;
        uint32_t adjustHoldTimeoutMs = 0;
        bool stepStarted = false;
        bool keysReleased = false;
        int32_t currentValue = 0;
        bool increasing = false;
        bool adjustTimedOut = false;
        char displayBeforeKeyPress[9] = {0};
        SettingWriteRequest request = {};
    };

    extern SettingWriterState g_state;
    extern char g_lastCompletedKey[4];
    extern uint32_t g_lastCompletedMs;
    extern int32_t g_lastCompletedValue;

    bool tryParseKey(const char *rawKey, char (&parsedKey)[4]);
    void startStep(uint32_t now, uint32_t keyMask);
    bool isWaitCompleted(uint32_t now, uint32_t ms);
    void releaseKeys(uint32_t now);
    void advanceToNextStep();
    void finishWrite();
    void abortWrite();
    bool updateInvalidDisplayTimer(uint32_t now);

} // namespace setting_writer_internal

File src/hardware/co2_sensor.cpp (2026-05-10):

#include "hardware/co2_sensor.h"

#include <cmath>

#include <Wire.h>

#include "hardware/pins.h"

namespace {
constexpr uint8_t kScd41Address = 0x62;
constexpr uint16_t kCommandSetAutomaticSelfCalibration = 0x2416;
constexpr uint16_t kCommandStopPeriodicMeasurement = 0x3F86;
constexpr uint16_t kCommandStartPeriodicMeasurement = 0x21B1;
constexpr uint16_t kCommandReadMeasurement = 0xEC05;
constexpr uint16_t kCommandGetDataReadyStatus = 0xE4B8;
constexpr uint32_t kPowerUpSettleMs = 1500;
constexpr uint32_t kInitRetryIntervalMs = 5000;
constexpr uint32_t kPollIntervalMs = 1000;
constexpr uint32_t kFirstSampleTimeoutMs = 15000;
constexpr uint32_t kStopMeasurementSettleMs = 500;

TwoWire &g_wire = Wire;

bool g_connected = false;
bool g_measuring = false;
bool g_dataValid = false;
uint16_t g_co2Ppm = 0;
float g_temperatureC = 0.0f;
float g_humidityPct = 0.0f;
float g_absoluteHumidityGm3 = 0.0f;
uint32_t g_lastSampleMs = 0;
uint32_t g_nextInitAttemptMs = 0;
uint32_t g_lastPollMs = 0;
uint32_t g_measurementStartedMs = 0;
const char *g_error = "not initialized";

uint8_t crc8(const uint8_t *data, size_t length) {
  uint8_t crc = 0xFF;

  for (size_t index = 0; index < length; ++index) {
    crc ^= data[index];
    for (uint8_t bit = 0; bit < 8; ++bit) {
      crc = (crc & 0x80U) != 0U ? static_cast<uint8_t>((crc << 1U) ^ 0x31U)
                                : static_cast<uint8_t>(crc << 1U);
    }
  }

  return crc;
}

bool writeCommand(uint16_t command) {
  g_wire.beginTransmission(kScd41Address);
  g_wire.write(static_cast<uint8_t>(command >> 8));
  g_wire.write(static_cast<uint8_t>(command & 0xFF));
  return g_wire.endTransmission() == 0;
}

bool probeSensor() {
  g_wire.beginTransmission(kScd41Address);
  return g_wire.endTransmission() == 0;
}

bool writeCommandWithWord(uint16_t command, uint16_t value) {
  const uint8_t payload[2] = {
      static_cast<uint8_t>(value >> 8),
      static_cast<uint8_t>(value & 0xFF),
  };

  g_wire.beginTransmission(kScd41Address);
  g_wire.write(static_cast<uint8_t>(command >> 8));
  g_wire.write(static_cast<uint8_t>(command & 0xFF));
  g_wire.write(payload[0]);
  g_wire.write(payload[1]);
  g_wire.write(crc8(payload, 2));
  return g_wire.endTransmission() == 0;
}

bool readWords(uint16_t command, uint16_t *words, size_t wordCount) {
  if (!writeCommand(command)) {
    return false;
  }

  delay(1);

  const size_t byteCount = wordCount * 3U;
  if (g_wire.requestFrom(static_cast<int>(kScd41Address), static_cast<int>(byteCount)) != static_cast<int>(byteCount)) {
    return false;
  }

  for (size_t index = 0; index < wordCount; ++index) {
    uint8_t bytes[2];
    bytes[0] = g_wire.read();
    bytes[1] = g_wire.read();
    const uint8_t receivedCrc = g_wire.read();
    if (crc8(bytes, 2) != receivedCrc) {
      return false;
    }
    words[index] = (static_cast<uint16_t>(bytes[0]) << 8) | bytes[1];
  }

  return true;
}

void setDisconnected(const char *error) {
  g_connected = false;
  g_measuring = false;
  g_error = error;
  g_nextInitAttemptMs = millis() + kInitRetryIntervalMs;
}

bool disableSelfCalibration() {
  // ASC is a volatile setting unless persist_settings is sent. Reapplying it
  // before measurement start keeps EEPROM untouched and also covers sensor
  // re-initialization after brownouts or I2C recovery.
  if (!writeCommandWithWord(kCommandSetAutomaticSelfCalibration, 0)) {
    setDisconnected("disable ASC failed");
    return false;
  }

  return true; 
}

bool resumeMeasurementIfRunning() {
  uint16_t readyWord = 0;
  if (!readWords(kCommandGetDataReadyStatus, &readyWord, 1)) {
    return false;
  }

  g_connected = true;
  g_measuring = true;
  g_measurementStartedMs = millis();
  g_error = (readyWord & 0x07FFU) != 0U ? "resumed" : "waiting for sample";
  g_lastPollMs = 0;
  return true;
}

bool startMeasurement(bool allowResume = true) {
  if (!probeSensor()) {
    setDisconnected("sensor probe failed");
    return false;
  }

  if (allowResume && resumeMeasurementIfRunning()) {
    return true;
  }

  // The SCD41 can still be in periodic mode after an ESP32-only reset.
  // Bring it back to idle before sending configuration commands.
  if (writeCommand(kCommandStopPeriodicMeasurement)) {
    delay(kStopMeasurementSettleMs);
  }

  if (!disableSelfCalibration()) {
    return false;
  }

  if (!writeCommand(kCommandStartPeriodicMeasurement)) {
    setDisconnected("start measurement failed");
    return false;
  }

  g_connected = true;
  g_measuring = true;
  g_measurementStartedMs = millis();
  g_error = "warming up";
  g_lastPollMs = 0;
  return true;
}

bool isDataReady() {
  uint16_t readyWord = 0;
  if (!readWords(kCommandGetDataReadyStatus, &readyWord, 1)) {
    setDisconnected("ready check failed");
    return false;
  }

  return (readyWord & 0x07FFU) != 0U;
}

bool readMeasurement() {
  uint16_t words[3] = {0, 0, 0};
  if (!readWords(kCommandReadMeasurement, words, 3)) {
    setDisconnected("measurement read failed");
    return false;
  }

  g_dataValid = true;
  g_co2Ppm = words[0];
  g_temperatureC = -45.0f + (175.0f * static_cast<float>(words[1]) / 65536.0f);
  g_humidityPct = 100.0f * static_cast<float>(words[2]) / 65536.0f;
  const float saturationVaporPressureHpa = 6.112f * std::exp((17.67f * g_temperatureC) / (g_temperatureC + 243.5f));
  const float vaporPressureHpa = saturationVaporPressureHpa * (g_humidityPct / 100.0f);
  g_absoluteHumidityGm3 = 216.7f * (vaporPressureHpa / (g_temperatureC + 273.15f));
  g_lastSampleMs = millis();
  g_error = "ok";
  return true;
}
}

void co2SensorSetup() {
  g_wire.begin(pins::kI2cSda, pins::kI2cScl, 100000U);
  g_nextInitAttemptMs = millis() + kPowerUpSettleMs;
  g_error = "power-up settle";
}

void co2SensorLoop() {
  const uint32_t now = millis();

  if (!g_measuring) {
    if (now < g_nextInitAttemptMs) {
      return;
    }

    startMeasurement();
    return;
  }

  if (!g_dataValid && now - g_measurementStartedMs >= kFirstSampleTimeoutMs) {
    startMeasurement(false);
    return;
  }

  if (now - g_lastPollMs < kPollIntervalMs) {
    return;
  }

  g_lastPollMs = now;

  if (!isDataReady()) {
    return;
  }

  readMeasurement();
}

Co2SensorStatus getCo2SensorStatus() {
  return {
      .connected = g_connected,
      .measuring = g_measuring,
      .dataValid = g_dataValid,
      .co2Ppm = g_co2Ppm,
      .temperatureC = g_temperatureC,
      .humidityPct = g_humidityPct,
      .absoluteHumidityGm3 = g_absoluteHumidityGm3,
      .lastSampleMs = g_lastSampleMs,
      .error = g_error,
  };
}

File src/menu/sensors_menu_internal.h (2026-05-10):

#pragma once

#include <Arduino.h>

#include "display/display_text_utils.h"
#include "menu/sensors_menu.h"

namespace sensors_menu_internal {

constexpr uint8_t kMaxUnknownSensors = 8;
constexpr uint8_t kFirstSensorsStep = 1;
constexpr uint8_t kLastSensorsStep = 16;
constexpr uint8_t kSensorsStepCount = kLastSensorsStep - kFirstSensorsStep + 1U;
constexpr uint8_t kLogicalValueCount = 17;
constexpr uint32_t kAutoScanIntervalMs = 60000;

struct SensorsMenuState
{
    bool running = false;
    uint8_t currentStep = 0;
    uint8_t currentScriptIndex = 0;
    uint32_t phaseStartedMs = 0;
    bool stepStarted = false;
    bool keysReleased = false;
    char firstEntryKey[4] = {0};
    char currentEntryKey[4] = {0};
    SensorsMenuCapturedEntry entries[kSensorsStepCount] = {};
    SensorsMenuUnknownEntry unknownEntries[kMaxUnknownSensors] = {};
};

extern portMUX_TYPE g_menuMux;
extern SensorsMenuState g_scanState;
extern SensorsMenuCapturedEntry g_lastCompletedEntries[kSensorsStepCount];
extern SensorsMenuUnknownEntry g_lastCompletedUnknownEntries[kMaxUnknownSensors];
extern uint32_t g_lastCompletedMs;
extern uint32_t g_lastScanStartedMs;

bool captureCurrentEntry(const char *displayText, const ParsedSensorEntry &parsedEntry);
bool captureCurrentEntry(const char *displayText);
void buildLogicalValues(const SensorsMenuCapturedEntry (&entries)[kSensorsStepCount], SensorsMenuValueItem (&values)[kLogicalValueCount]);
void runCurrentStep(uint32_t now);

} // namespace sensors_menu_internal

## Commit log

2026-04-06 Working version. With reading / writing values
    [Controller.kicad_pcb, Controller.kicad_sch, Display.kicad_pcb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]
2026-04-06 Refactor tasks and enhance key handling logic
    - Updated task arguments in tasks.json for better readability.
    - Enabled auto scan for sensors in app_config.h.
    - Updated build ID in build_info.generated.h.
    - Added auto-release functionality in key_writer.cpp.
    - Introduced pulseKeys function in key_writer.h for key press duration control.
    - Improved sensors menu logic to handle startup scan state.
    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
2026-04-06 Implement MQTT configuration management and enhance reset info handling
    [main.cpp, reset_info.cpp]
2026-04-07 Add MQTT discovery functionality and entity definitions
    - Introduced ha_entity_definitions.h to define entity structures and enums for Home Assistant integration.
    - Implemented mqtt_discovery.cpp to handle MQTT connection, message processing, and state publishing for various entities.
    - Created mqtt_discovery.h for function declarations related to MQTT discovery setup and loop.
    - Added mqtt_discovery_payload.cpp and mqtt_discovery_payload.h to manage the construction of discovery payloads using ArduinoJson.
    - Enhanced command handling for settings and ventilation modes, including queuing and processing commands.
    - Implemented functions to publish CO2 sensor data, settings, and sensor menu st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
2026-05-03 update hardware
    [RvSensor.kicad_sch, Sensor.kicad_pcb, Sensor.kicad_sch]
2026-05-04 Fix spikes on co2 sensor when reset/reboot
    [co2_sensor.cpp]
2026-05-04 Update readme met mermaid flow
2026-05-04 Fxi unknown entries in sensor menu, cleanup mqtt
2026-05-05 Add Optie print docs
2026-05-05 fix sensor reader
2026-05-09 fix ha change setting. Do not set old values before finish update. Add Optionprint sensors
    [sensors_menu_internal.h]
2026-05-09 Fix increase timeout on write settings. Fix hang in write setting on out of range values
    [setting_writer_internal.h]
2026-05-10 cleanup menu readers fix outofRange values
    [display_reader.cpp, key_writer.cpp]
2026-05-10 cleanup sensor menu and setting writer
